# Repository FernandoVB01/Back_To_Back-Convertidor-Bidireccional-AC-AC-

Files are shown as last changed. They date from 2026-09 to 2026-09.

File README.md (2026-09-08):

# Convertidor Back-to-Back (AFE + Inversor) — 15 kVA / 800 V

Convertidor trifásico regenerativo completo: rectificador activo (AFE) +
inversor con control vectorial, bus DC común, control en **STM32G474** y
telemetría en **ESP32-S3**. Diseño en KiCad 9, validado por simulación.

**Punto de diseño:** 15 kVA · 400 V_LL · 60 Hz · V_dc ≤ 800 V · f_sw 16 kHz.

---

## Cómo lo ejecuto

```powershell
powershell -ExecutionPolicy Bypass -File .\run.ps1
```

Eso hace **todo** en orden. Tarda unos minutos (lo más lento es LTspice).

Por etapas, si solo quieres una parte:

```powershell
.\run.ps1 check    # comprobar que están las herramientas (empieza por aquí)
.\run.ps1 sim      # simulación y validación   -> docs/INFORME_VALIDACION.md
.\run.ps1 spice    # LTspice                   -> sim/out/06..08*.png
.\run.ps1 fw       # firmware: genera b2b_config.h
.\run.ps1 kicad    # esquemático + PCB + render 3D
.\run.ps1 mech     # gabinete
```

### ⚠ Lo único que hay que entender: hay DOS Python

No son intercambiables. `run.ps1` elige el correcto en cada paso, pero si
lanzas algo a mano tienes que saberlo:

| Python | Dónde | Para qué |
|---|---|---|
| **El de KiCad** | `C:\Program Files\KiCad\9.0\bin\python.exe` | `tools/gen_schematic.py`, `gen_pcb.py`, `check_conn.py`, `restore_pro.py` — necesitan el módulo `pcbnew` |
| **Anaconda** | `python` (en el PATH) | `sim/`, `spice/`, `mech/`, `fw/`, `tools/gen_kicad_sim.py`, `verify_kicad_sim.py` — necesitan numpy/scipy/matplotlib |

Si un script falla con `ModuleNotFoundError: pcbnew` o
`ModuleNotFoundError: numpy`, es que lo has lanzado con el Python equivocado.

### Requisitos

- **KiCad 9.0** en `C:\Program Files\KiCad\9.0` (trae su Python y `kicad-cli`)
- **Anaconda** con numpy, scipy, matplotlib
- **LTspice** (ADI) en `%LOCALAPPDATA%\Programs\ADI\LTspice\` — solo para la
  etapa `spice`; el resto funciona sin él

---

## Qué hay en cada carpeta

```
kicad/      PROYECTO KICAD  <- abre b2b_converter.kicad_pro
  sch/        11 subhojas del esquemático
  sim/        esquemas simulables con ngspice (Inspeccionar > Simulador)
sim/        simulación y validación en Python (la fuente de la verdad)
spice/      netlists de LTspice (se abren también a mano en LTspice)
fw/         firmware del STM32G474
mech/       gabinete industrial
tools/      los generadores (nada de esto se editó a mano)
docs/       toda la documentación
render/     renders 3D de la PCB
export/     PDF de los planos, informes de ERC y DRC
```

## Por dónde empezar a leer

| Documento | Qué te cuenta |
|---|---|
| [docs/INFORME_VALIDACION.md](docs/INFORME_VALIDACION.md) | Las 31 comprobaciones del diseño, con los números |
| [docs/ESTADO_KICAD.md](docs/ESTADO_KICAD.md) | Qué está hecho en la PCB y qué falta |
| [docs/BOM_INDUSTRIAL.md](docs/BOM_INDUSTRIAL.md) | Componentes con marca y referencia real |
| [docs/COMO_SIMULAR.md](docs/COMO_SIMULAR.md) | **Cómo lanzar las 4 simulaciones y qué mirar en cada una** |
| [docs/RUTEO_ESTADO.md](docs/RUTEO_ESTADO.md) | Estado del ruteo y los bugs que destapó |
| [docs/SIMULAR_FIRMWARE.md](docs/SIMULAR_FIRMWARE.md) | Por qué Proteus no sirve aquí y qué se hace en su lugar |
| [docs/00_MASTER_PLAN.md](docs/00_MASTER_PLAN.md) | Arquitectura y las 6 fases del proyecto |
| [docs/KICAD_PCB_FLOORPLAN.md](docs/KICAD_PCB_FLOORPLAN.md) | Stackup, floorplan y orden de ruteo |

---

## La regla de oro del proyecto

**Todo sale de `sim/b2b_params.py`.** Ese archivo es la única fuente de
parámetros:

```
sim/b2b_params.py
   ├──► sim/run_all.py        ──► validación (31 comprobaciones)
   ├──► spice/gen_spice.py    ──► SPICE
   ├──► fw/config/gen_config.py ──► b2b_config.h ──► firmware C
   │                                     └──► control_ref.py (verificación)
   ├──► tools/gen_schematic.py ──► esquemático KiCad
   └──► mech/gen_gabinete.py  ──► gabinete
```

Si cambias un parámetro ahí y ejecutas `.\run.ps1`, se regenera todo y nada
se desincroniza. **No edites a mano el esquemático ni `b2b_config.h`**: los
sobrescribe el generador.

## Estado

- Esquemático: **227 componentes**, 0 cables sueltos. Bus DC corregido:
  `DC_P` pasó de 4 a **22 pads** (los rieles solo conectaban la última rama)
- PCB: 340×240 mm, 4 capas, footprints colocados y zonas rellenadas
- **Ruteo de pistas: 0 %** — ver [docs/RUTEO_ESTADO.md](docs/RUTEO_ESTADO.md): el auto-ruteador propio se descartó por introducir cortocircuitos
- Validación: **31/31 comprobaciones OK**
- Firmware: matemática de control y configuración listas; falta la capa HAL

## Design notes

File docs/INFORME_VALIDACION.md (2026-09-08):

# Informe de validacion del convertidor back-to-back

> Generado por `sim/run_all.py`. No editar a mano: cambia `sim/b2b_params.py` y vuelve a ejecutarlo.

```
PUNTO DE DISENO
  S = 15 kVA | 400 V_LL | 60 Hz | I_n = 21.65 A
  Bus DC = 700 V (max 800 V) | C_bus = 600 uF
  f_sw = 16 kHz | T_s = 62.5 us | dead-time = 500 ns
  LCL: L1 = 1.50 mH | Cf = 10.0 uF | Rd = 6.8 ohm | L2 = 0.60 mH
  SiC: C3M0075120K (75 mOhm) x 12
  Motor: PMSM p=3 lambda=0.35 Wb Kt=1.575 Nm/A J=0.02 kg m2
```

## Resultado global

**38 de 38 comprobaciones OK.**

## 1. Filtro LCL y calidad de red

| | Comprobacion | Valor | Limite | Nota |
|:-:|---|---:|---:|---|
| **OK** | Resonancia LCL | 2431 Hz | 600 .. 8000 | debe estar entre 10*fg y fsw/2 |
| **OK** | Atenuacion extra a f_sw vs L unica | -15.853 dB | -12.000 | compromiso con el amortiguamiento; el criterio normativo real es la THD |
| **OK** | Rizado en L1 (pico-pico) | 11.907 % | 25.000 | 3.65 A sobre 30.6 A pico |
| **OK** | Reactiva del banco Cf | 4.021 % | 5.000 | 603 var |
| **OK** | Pico en resonancia (amortiguado) | 19.200 dB | 20.000 | sin Rd seria 69 dB |
| **OK** | Disipacion en las 3 Rd | 12.202 W | 30.000 | usar 10 W por resistencia |
| **OK** | THD de corriente de red (estimada) | 0.245 % | 5.000 | IEEE 519 / IEC 61000-3-12 |

## 2. Estabilidad de los lazos de control

| | Comprobacion | Valor | Limite | Nota |
|:-:|---|---:|---:|---|
| **OK** | Lazo de corriente: ancho de banda | 849.389 Hz | 800 .. 2667 | Kp = 11.200  Ki = 266.7 |
| **OK** | Lazo de corriente: margen de fase | 61.333 grados | 45.000 |  |
| **OK** | Lazo de corriente: margen de ganancia | 9.934 dB | 6.000 |  |
| **OK** | Lazo de bus DC: ancho de banda | 141.425 Hz | 10 .. 169.9 | Kp = 0.7623  Ki = 225.946 |
| **OK** | Lazo de bus DC: margen de fase | 53.130 grados | 45.000 |  |

## 3. Termico (C3M0075120K, el de la libreria)

| | Comprobacion | Valor | Limite | Nota |
|:-:|---|---:|---:|---|
| **OK** | Perdidas por dispositivo (C3M0075120K) | 28.131 W | 40.000 | cond 22.8 + conm 4.1 + diodo 1.3 |
| **OK** | Perdidas totales de semiconductores | 337.577 W | 400.000 | 12 dispositivos |
| **OK** | Rth disipador-ambiente requerida | 0.162 C/W | 0.150 | por debajo de 0.15 C/W ya no es viable con aire |
| **OK** | Rendimiento estimado | 97.418 % | 96.000 |  |

## 3b. Termico (C3M0040120K, el recomendado)

| | Comprobacion | Valor | Limite | Nota |
|:-:|---|---:|---:|---|
| **OK** | Perdidas por dispositivo (C3M0040120K) | 17.514 W | 40.000 | cond 12.1 + conm 4.1 + diodo 1.3 |
| **OK** | Perdidas totales de semiconductores | 210.169 W | 400.000 | 12 dispositivos |
| **OK** | Rth disipador-ambiente requerida | 0.306 C/W | 0.150 | por debajo de 0.15 C/W ya no es viable con aire |
| **OK** | Rendimiento estimado | 98.231 % | 96.000 |  |

## 4. Precarga del bus

| | Comprobacion | Valor | Limite | Nota |
|:-:|---|---:|---:|---|
| **OK** | Corriente de inrush | 8.319 A | 10.000 |  |
| **OK** | Constante de tiempo de precarga | 40.800 ms | 200.000 | 95 % en 122 ms |
| **OK** | Energia en Rpc por carga | 96.000 J | 400.000 | pico instantaneo 4.7 kW |

## 5. Simulacion temporal + frenado regenerativo

| | Comprobacion | Valor | Limite | Nota |
|:-:|---|---:|---:|---|
| **OK** | Error de regulacion del bus (motorizando) | 0.0006843 % | 1.000 | media 700.0 V |
| **OK** | Rizado del bus en regimen | 0.00455 % | 2.000 |  |
| **OK** | Pico de bus durante el frenado | 701.611 V | 800.000 | chopper en 770 V, disparo en 800 V |
| **OK** | Factor de potencia en la red | 1.000  | 0.990 | Id = 21.06 A, Iq = -0.000 A |
| **OK** | Potencia de red motorizando | 10.315 kW | 0.000 | positiva = consume de la red |
| **OK** | Potencia de red frenando | -5.938 kW | 0.000 | NEGATIVA = devuelve a la red (regenera) |
| **OK** | Error maximo del PLL tras enganche | 6.183e-12 grados | 1.000 |  |
| **OK** | Error de velocidad en regimen | 9.368e-05 % | 2.000 | 250.0 rad/s de 250 rad/s |

## 6. Respuesta dinamica, rendimiento y armonicos

| | Comprobacion | Valor | Limite | Nota |
|:-:|---|---:|---:|---|
| **OK** | Sobreimpulso del lazo de corriente | 4.052 % | 20.000 |  |
| **OK** | Tiempo de establecimiento del bus | 8.862 ms | 50.000 | al 2 % |
| **OK** | Caida del bus ante escalon de carga (con FF) | 6.326 V | 14.000 | limite 2 % = 14 V |
| **OK** | Margen de modulo (distancia a -1) | 0.629  | 0.500 | > 0.5 es robusto |
| **OK** | THD con armonicos de baja frecuencia | 1.209 % | 5.000 | IEEE 519 |

## 7. Modulacion SVPWM

| | Comprobacion | Valor | Limite | Nota |
|:-:|---|---:|---:|---|
| **OK** | SVPWM: error del lugar geometrico en el limite lineal | 5.125e-10 % | 1.000 | debe ser un circulo de radio Vdc/sqrt(3) |
| **OK** | SVPWM: ganancia sobre SPWM senoidal | 15.470 % | 15.000 | teorico 15.47 % |

## Ganancias resultantes (llevar al firmware)

```c
/* Lazo de corriente del AFE y del inversor, 16 kHz */
#define KP_I     11.200000f
#define KI_I     266.666667f
/* Lazo externo de tension de bus */
#define KP_VDC   0.762316f
#define KI_VDC   225.946265f
#define TS       0.000062500f  /* 62.50 us */
```

## Figuras

### Respuesta del filtro LCL: resonancia, amortiguamiento y atenuacion a f_sw.

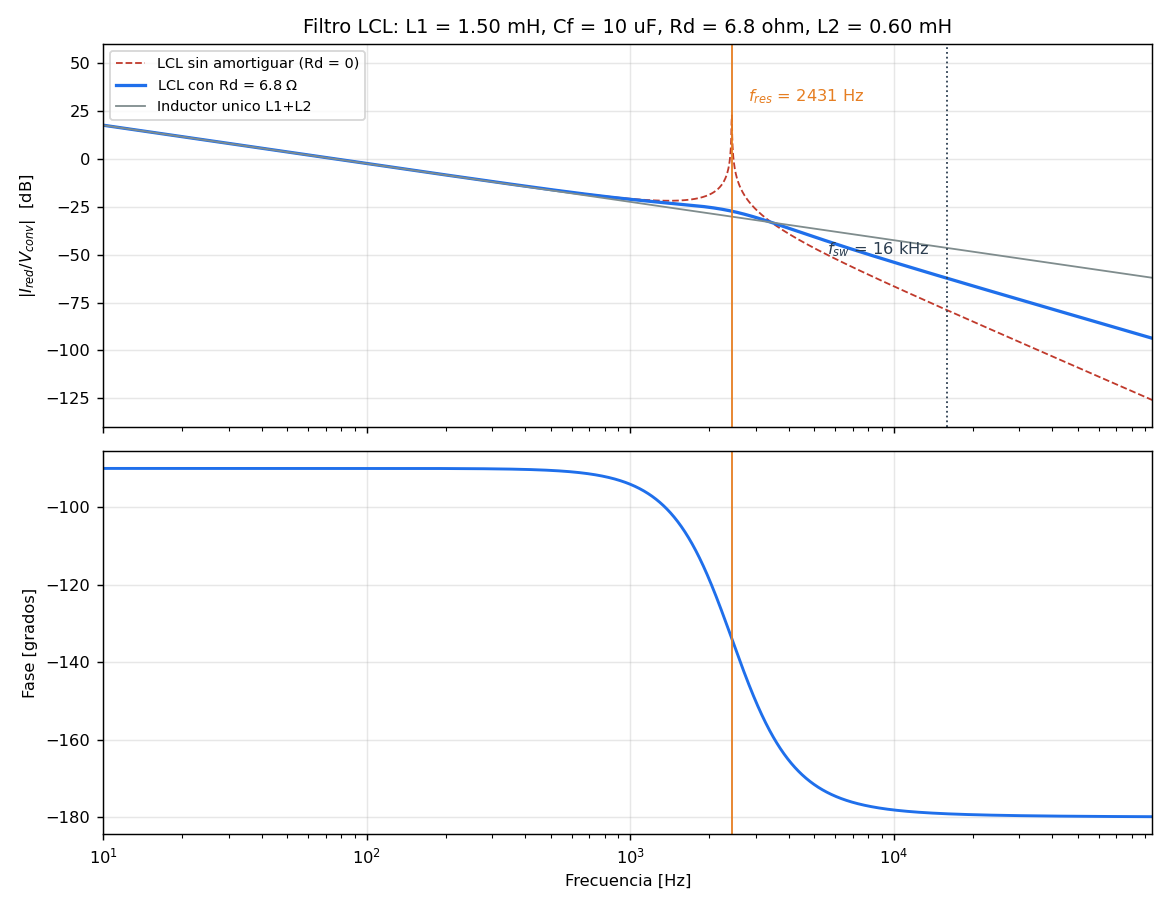
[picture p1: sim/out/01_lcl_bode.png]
Respuesta del filtro LCL: resonancia, amortiguamiento y atenuacion a f_sw.


### Bode de lazo abierto de los lazos de corriente y de bus, con el retardo de 1.5 Ts.

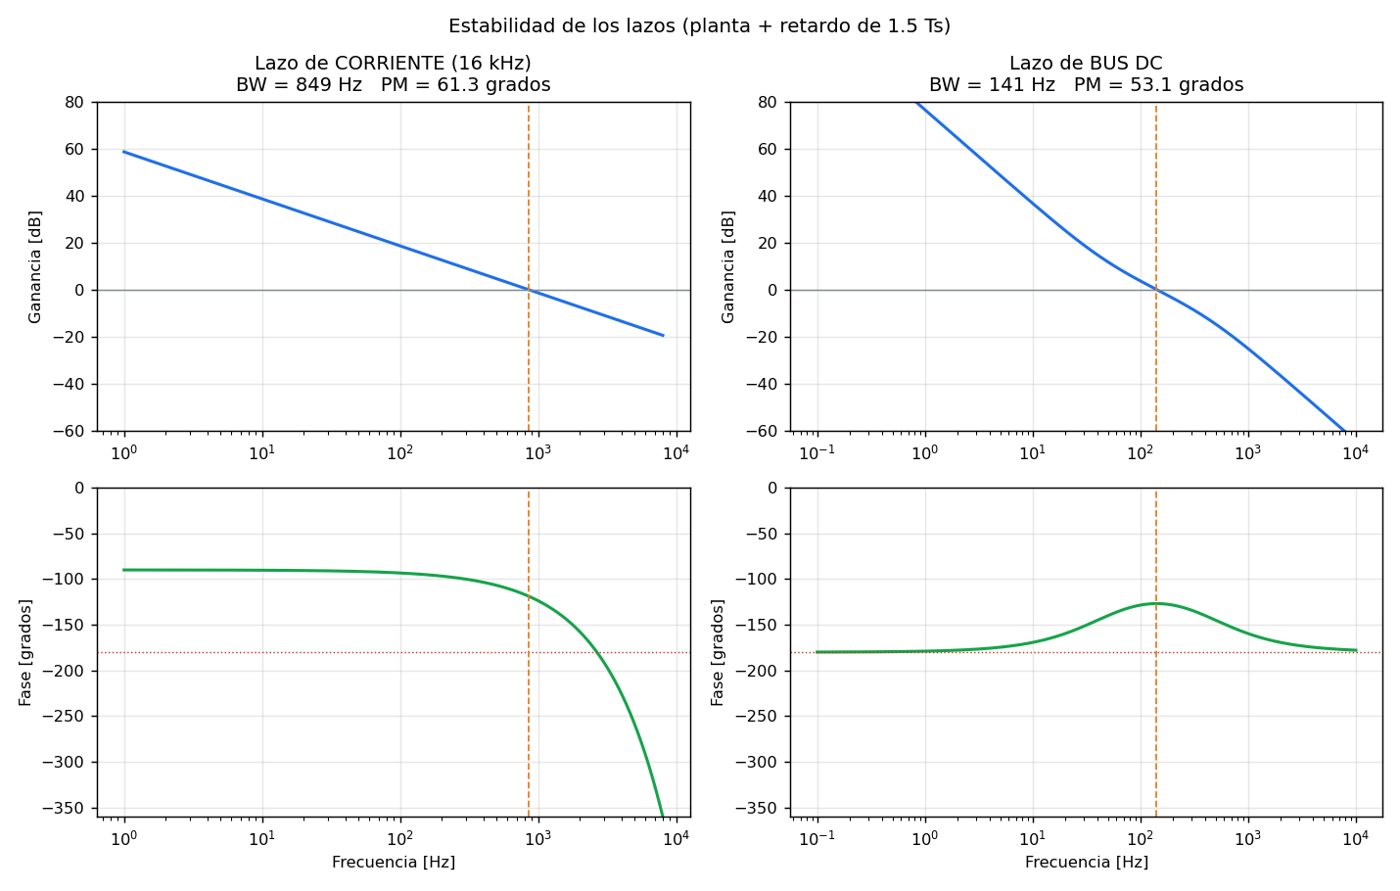
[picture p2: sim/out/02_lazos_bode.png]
Bode de lazo abierto de los lazos de corriente y de bus, con el retardo de 1.5 Ts.


### Transitorio de precarga: tension de bus e inrush.

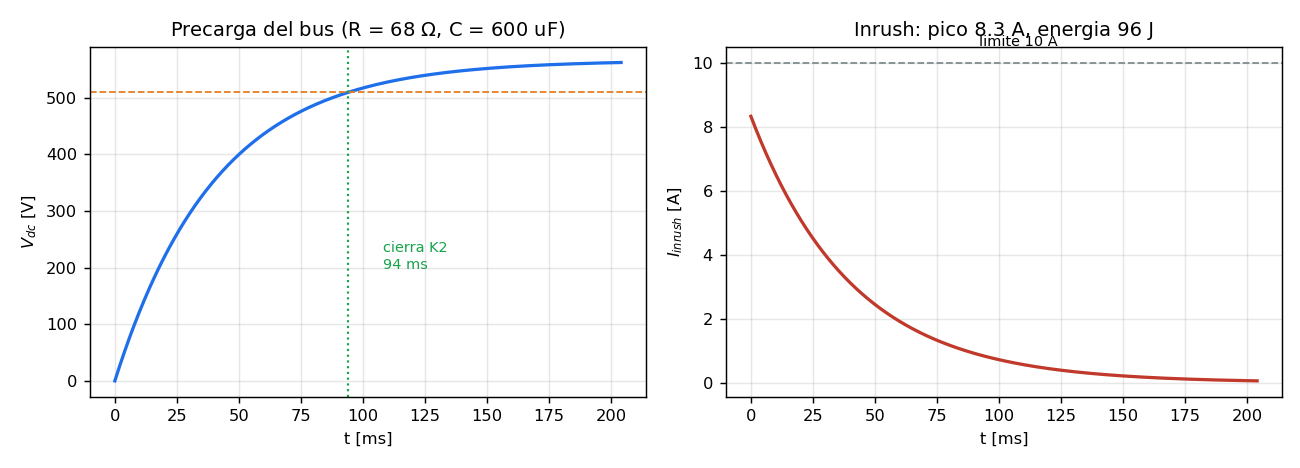
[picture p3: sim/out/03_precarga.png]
Transitorio de precarga: tension de bus e inrush.


### Simulacion completa: bus, motor, flujo de potencia y corriente dq de red.

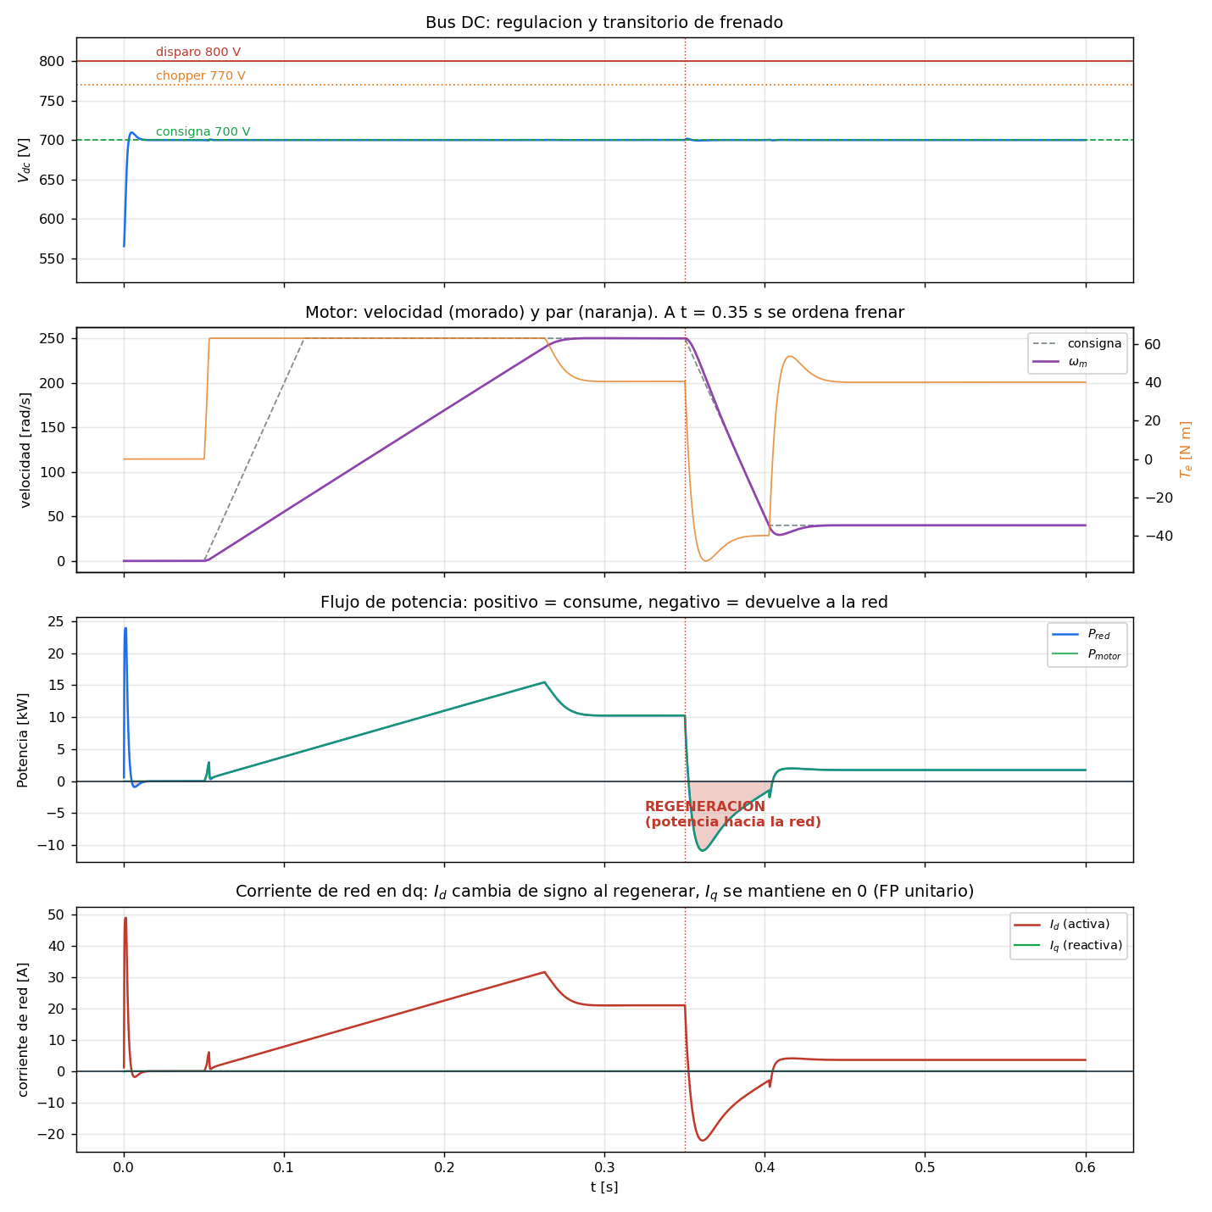
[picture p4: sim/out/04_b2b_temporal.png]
Simulacion completa: bus, motor, flujo de potencia y corriente dq de red.


### Prueba del frenado regenerativo: la corriente de red se invierte.

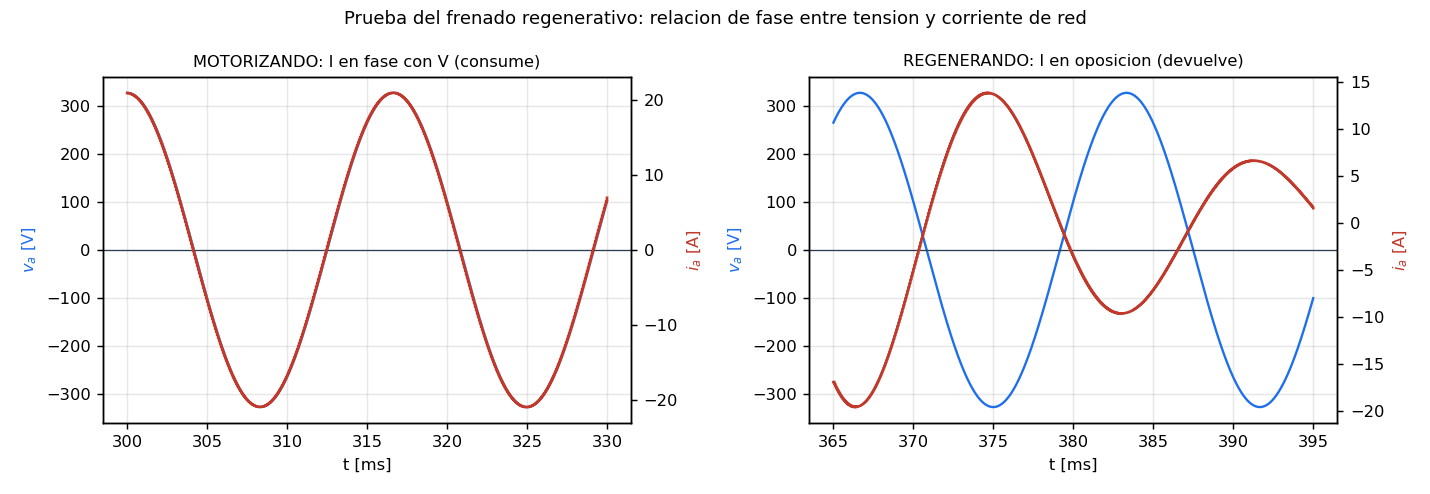
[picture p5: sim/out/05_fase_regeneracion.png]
Prueba del frenado regenerativo: la corriente de red se invierte.


### Respuesta al escalon en lazo cerrado: sobreimpulso y tiempo de establecimiento.

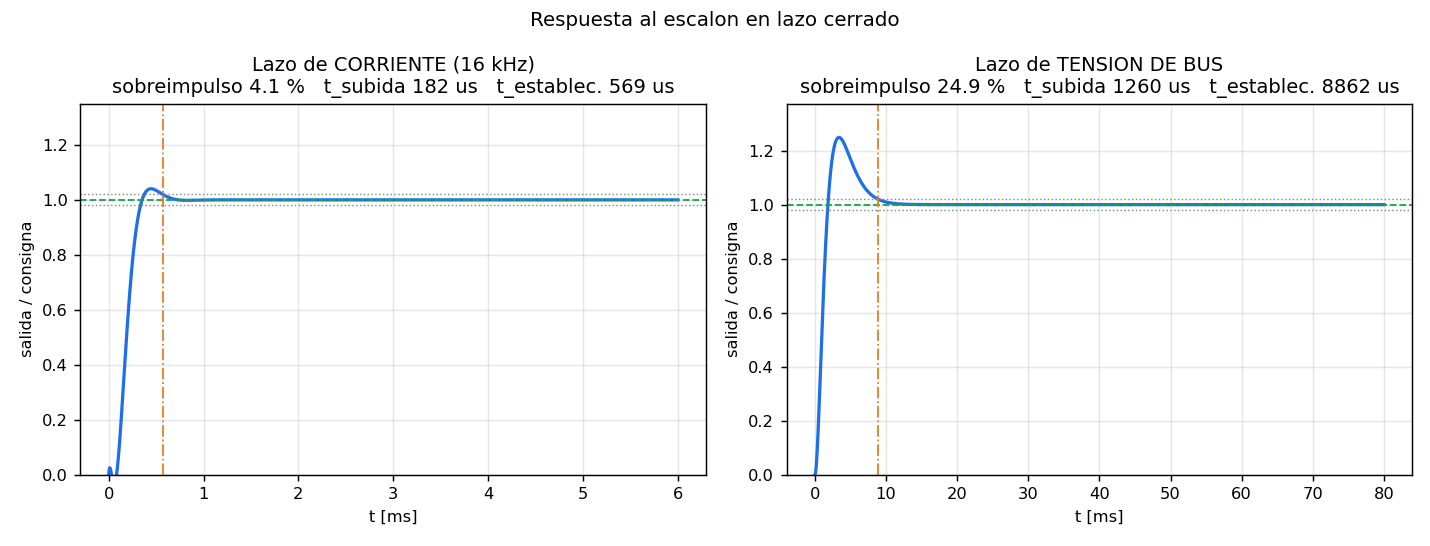
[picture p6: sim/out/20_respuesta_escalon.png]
Respuesta al escalon en lazo cerrado: sobreimpulso y tiempo de establecimiento.


### CARGA TRANSITORIA: escalon de 20 % a 100 % y vuelta. Con y sin feedforward.

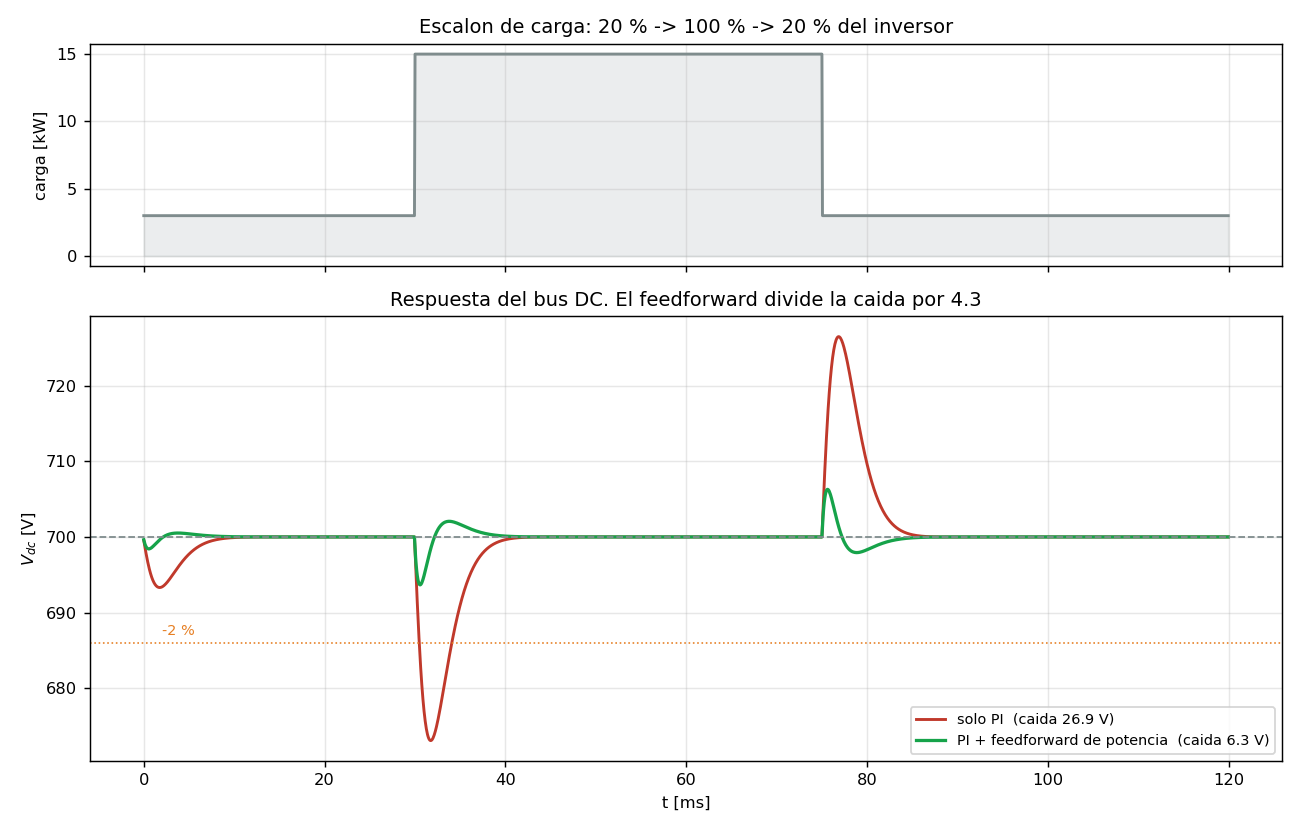
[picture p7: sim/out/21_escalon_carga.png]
CARGA TRANSITORIA: escalon de 20 % a 100 % y vuelta. Con y sin feedforward.


### Nyquist del lazo de corriente con el margen de modulo.

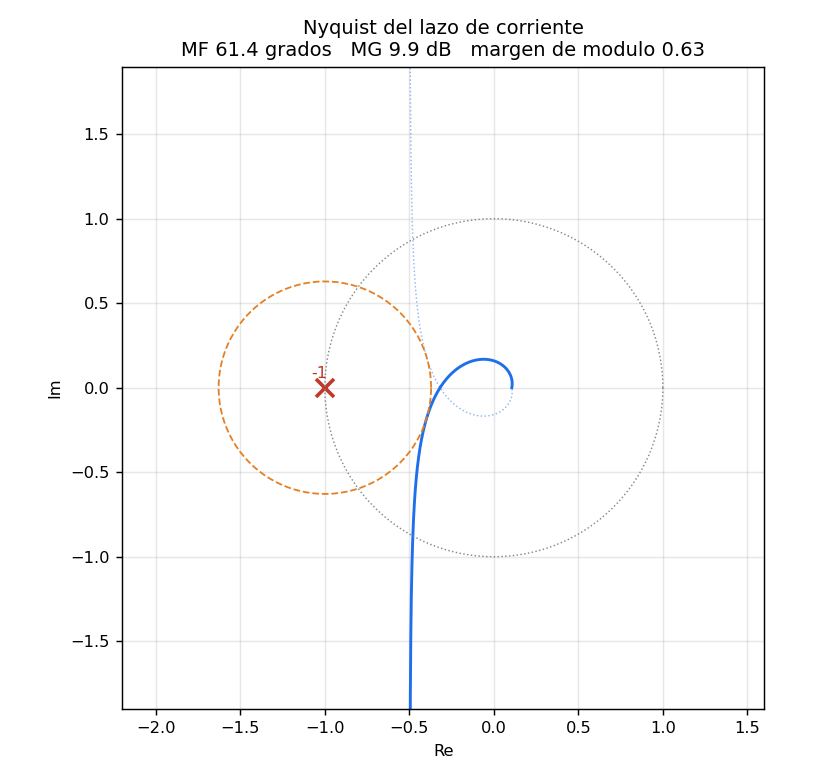
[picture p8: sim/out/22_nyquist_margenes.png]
Nyquist del lazo de corriente con el margen de modulo.


### Rendimiento vs carga y desglose de perdidas.

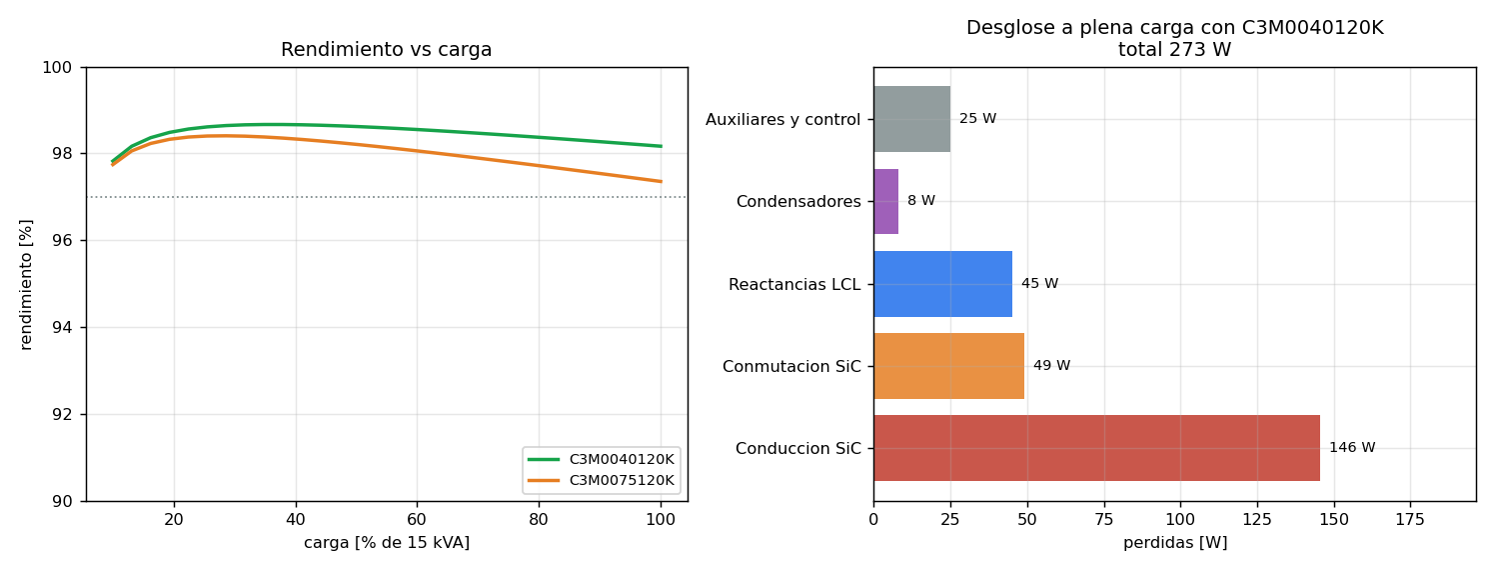
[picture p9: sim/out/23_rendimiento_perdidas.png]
Rendimiento vs carga y desglose de perdidas.


### Temperatura de union vs ambiente y curva de derating.

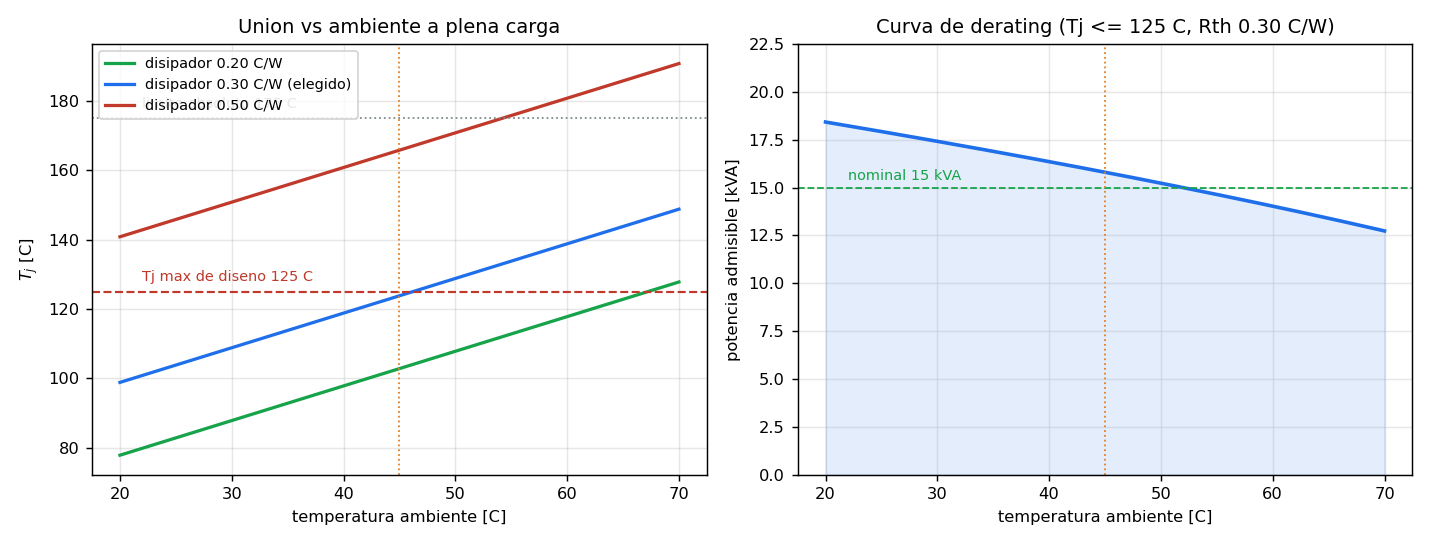
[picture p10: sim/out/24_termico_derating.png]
Temperatura de union vs ambiente y curva de derating.


### Espectro de la corriente de red contra los limites de IEEE 519.

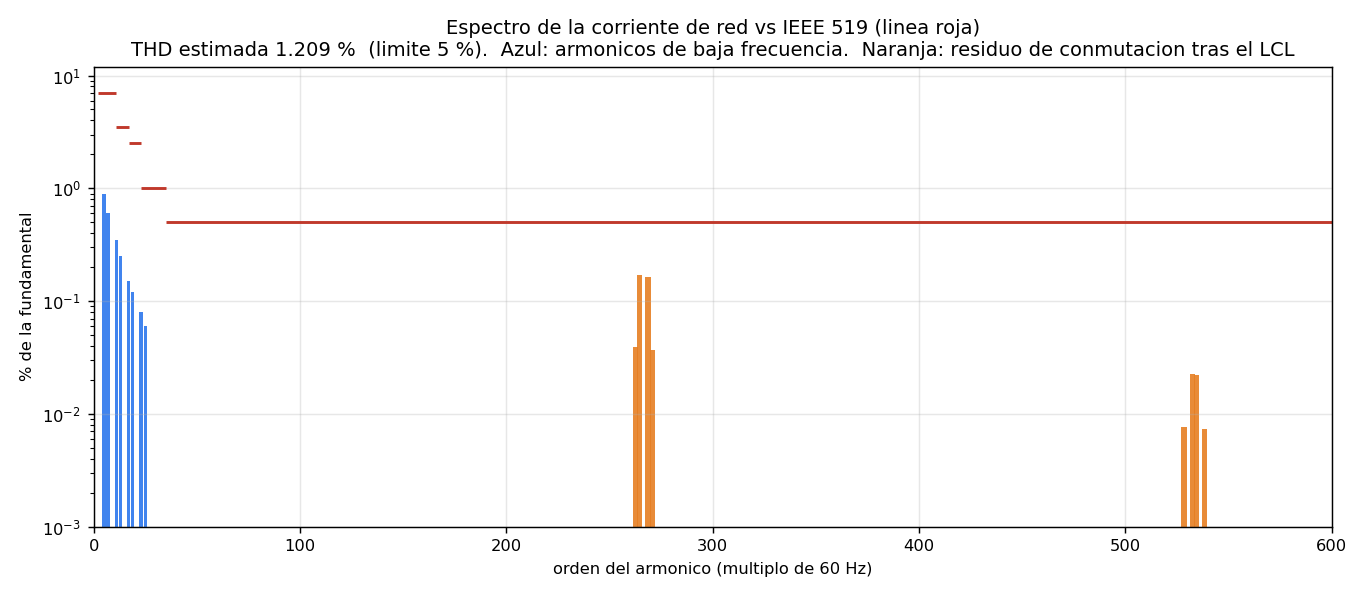
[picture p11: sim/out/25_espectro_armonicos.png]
Espectro de la corriente de red contra los limites de IEEE 519.


### SVPWM: hexagono, 6 sectores y los 8 estados. El lugar geometrico lo genera la funcion svpwm() del firmware.

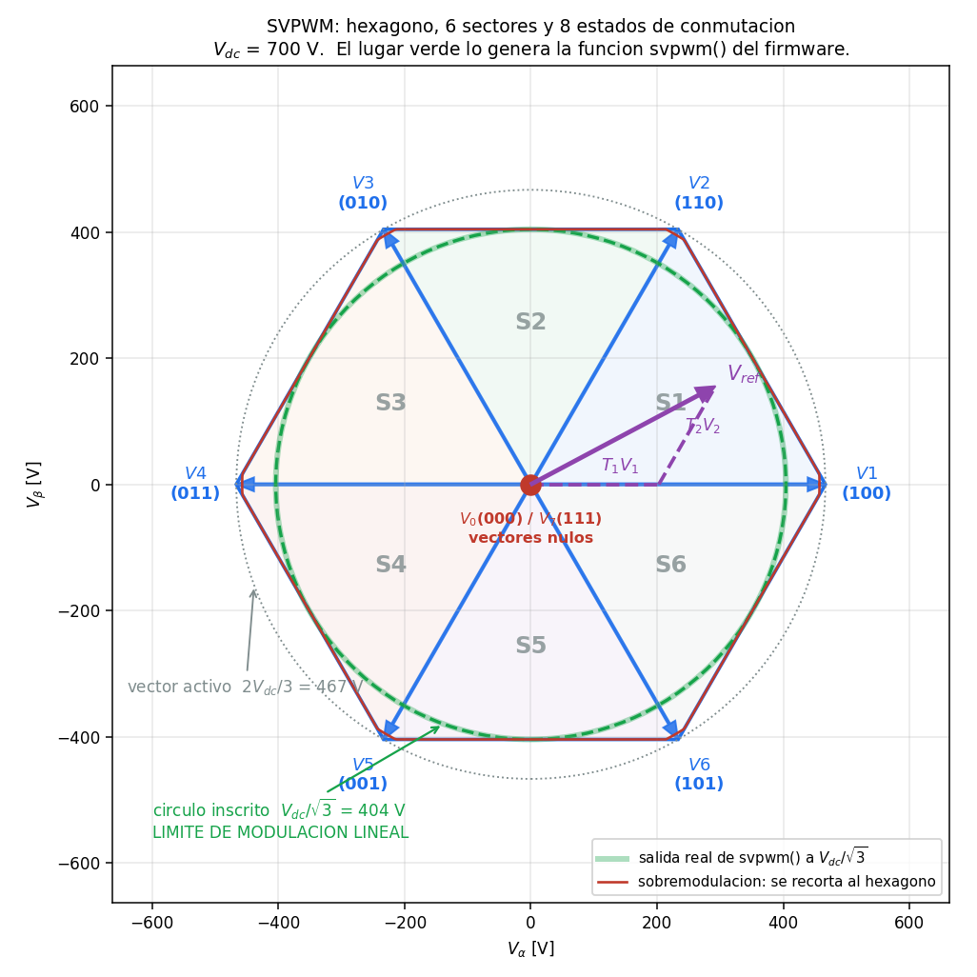
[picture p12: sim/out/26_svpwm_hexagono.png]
SVPWM: hexagono, 6 sectores y los 8 estados. El lugar geometrico lo genera la funcion svpwm() del firmware.


### Ciclos de trabajo vs angulo y patron simetrico de 7 segmentos en un periodo.

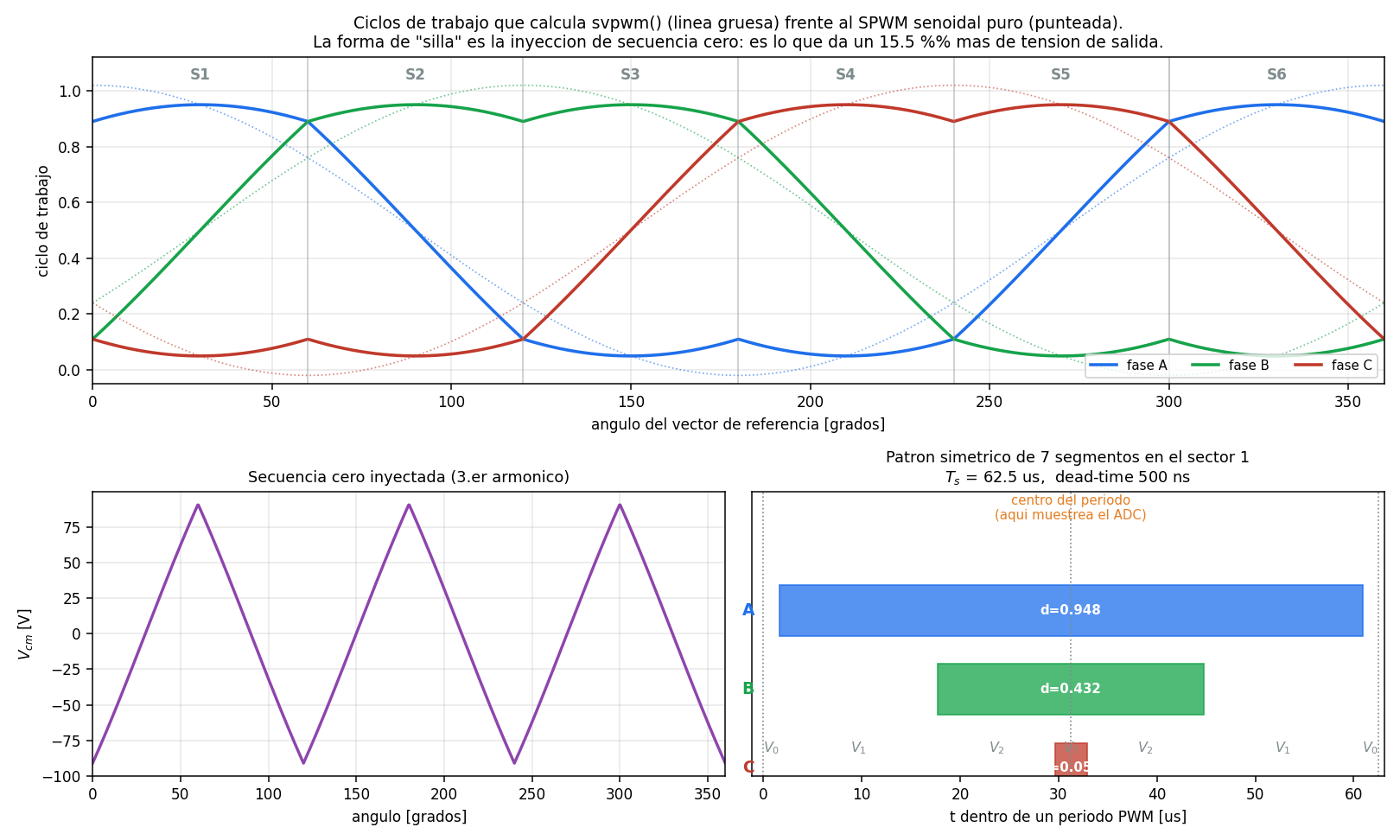
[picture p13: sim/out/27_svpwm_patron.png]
Ciclos de trabajo vs angulo y patron simetrico de 7 segmentos en un periodo.


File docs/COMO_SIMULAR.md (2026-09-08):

# Cómo ejecutar todas las simulaciones

> Hay **cuatro simuladores** distintos en este proyecto y cada uno responde a
> una pregunta diferente. Aquí está qué corre cada uno, cómo lanzarlo y qué
> deberías ver.

---

## Resumen: los cuatro simuladores

| # | Simulador | Responde a | Tarda |
|---|---|---|---|
| 1 | **Python** (`sim/`) | ¿El convertidor completo funciona? ¿Regenera de verdad? | 4 s |
| 2 | **LTspice** (`spice/`) | ¿Cuánta sobretensión mete el layout? ¿Cuál es el dv/dt real? | 2 min |
| 3 | **ngspice dentro de KiCad** (`kicad/sim/`) | Lo mismo, pero sobre el esquema dibujado | interactivo |
| 4 | **SIL del firmware** (`fw/verify/`) | ¿El código de control calcula bien? | 1 s |

**Todo de golpe:**

```powershell
powershell -ExecutionPolicy Bypass -File .\run.ps1
```

---

## 1. Simulación del sistema completo (Python)

La más importante: red → filtro LCL → AFE con PLL → bus DC → inversor con FOC
→ motor PMSM, con un **evento de frenado regenerativo**.

```powershell
.\run.ps1 sim
```
o directamente:
```powershell
python sim/b2b_params.py      # punto de diseno, solo imprime
python sim/sim_design.py      # figuras 01-03 (LCL, lazos, precarga)
python sim/sim_timedomain.py  # figuras 04-05 (convertidor completo)
python sim/sim_respuesta.py   # figuras 20-25 (escalon, Nyquist, termico)
python sim/sim_svpwm.py       # figuras 26-27 (hexagono y patron)
python sim/run_all.py         # todo + el informe
```

**Qué produce**
- `docs/INFORME_VALIDACION.md` — las 38 comprobaciones con sus números
- `sim/out/01_lcl_bode.png` — respuesta del filtro LCL
- `sim/out/02_lazos_bode.png` — Bode de los lazos con el retardo de 1.5·Ts
- `sim/out/03_precarga.png` — transitorio de precarga e inrush
- `sim/out/04_b2b_temporal.png` — **la simulación completa**
- `sim/out/05_fase_regeneracion.png` — tensión vs corriente de red

**Qué mirar en `04_b2b_temporal.png`** (de arriba abajo):
1. El bus DC clavado en **700 V**, sin acercarse ni al chopper (770) ni al disparo (800)
2. El motor acelerando a 250 rad/s; a t = 0.35 s se ordena frenar
3. La potencia de red cruzando a **negativo (−11 kW)** → está devolviendo a la red
4. `Id` cambiando de signo mientras `Iq` sigue en 0 → **factor de potencia unitario**

Debe terminar en **`38/38 OK`**. Si alguna falla, el informe dice cuál y por qué.

### Cambiar el punto de diseño

Todo sale de `sim/b2b_params.py`. Cambia ahí la potencia, la tensión de red,
`f_sw`, los valores del LCL… y vuelve a lanzar. Se regeneran también el SPICE,
el `b2b_config.h` del firmware, el esquemático y el gabinete.

### Lanzar una sola parte

Cada modulo de `sim/` se ejecuta por separado y genera solo sus figuras.
**Ojo: hay que anteponer `python`** — un `.py` no es un comando de Windows.

```powershell
python sim/b2b_params.py      # punto de diseno, solo imprime
python sim/sim_design.py      # figuras 01-03 (LCL, lazos, precarga)
python sim/sim_timedomain.py  # figuras 04-05 (convertidor completo)
python sim/sim_respuesta.py   # figuras 20-25 (escalon, Nyquist, termico)
python sim/sim_svpwm.py       # figuras 26-27 (hexagono y patron)
python sim/run_all.py         # todo + el informe
```

Escribir solo `sim_design.py` da
`no se reconoce como un comando interno o externo`: Windows no ejecuta
scripts de Python directamente.

---

## 2. SPICE en LTspice

Lo que el modelo promediado no puede dar: el transitorio de conmutación real
con las **inductancias parásitas del layout**.

```powershell
.\run.ps1 spice
```
o:
```powershell
python spice\gen_spice.py
```

**Qué produce**
- `sim/out/06_spice_halfbridge.png` — sobretensión según la inductancia de lazo
- `sim/out/07_spice_lcl.png` — contraste del LCL: analítico vs SPICE
- `sim/out/08_spice_precarga.png` — precarga
- `spice/net/*.net` — los netlists, que **se pueden abrir a mano en LTspice**

**El resultado clave** (doble pulso a 700 V / 30 A):

| Inductancia de lazo | Pico en el nodo de conmutación |
|---:|---:|
| 5 nH | 753 V |
| **20 nH** (objetivo del floorplan) | **823 V** |
| 60 nH | 929 V |
| 150 nH | 1136 V ← al borde de romper el SiC de 1200 V |

Eso es lo que justifica numéricamente la regla de "lazo apretado".

### Abrirlos a mano en LTspice

```powershell
& "$env:LOCALAPPDATA\Programs\ADI\LTspice\LTspice.exe" spice\net\hb_20nH.net
```
Una vez abierto: **Simulate → Run**, y click en un nodo para graficarlo.

---

## 3. ngspice dentro de KiCad

Los mismos circuitos, pero dibujados como esquema de KiCad.

```powershell
python tools\gen_kicad_sim.py
```

Genera tres esquemas en `kicad/sim/`:

| Archivo | Análisis | Qué comprueba |
|---|---|---|
| `lcl_ac.kicad_sch` | `.ac dec 400 10 200k` | Resonancia en 2431 Hz, pico amortiguado de 19 dB |
| `halfbridge.kicad_sch` | `.tran 0.02n 5.2u` | Sobretensión según la parásita del lazo |
| `fw_bridge.kicad_sch` | `.tran 100n 187u` | Puente gobernado por el **PWM real del firmware** |

**Para simularlos:**
1. Abre el `.kicad_sch` en KiCad (doble clic)
2. **Inspeccionar → Simulador**
3. Botón **Ejecutar**
4. **Añadir señales** y elige qué graficar: `I(RL2)` en el LCL, `V(sw)` en el medio puente

El comando de análisis va escrito como texto en la propia hoja; puedes
editarlo ahí mismo.

### El interesante: `fw_bridge`

Sus seis fuentes de puerta **no son ondas inventadas**: son los flancos que
calcula el código de control real (SVPWM por inyección de secuencia cero) con
el dead-time de 500 ns del TIM1. KiCad **no ejecuta firmware** — no tiene
modelo de núcleo ARM — pero aquí su salida real gobierna el circuito.
Ver `docs/SIMULAR_FIRMWARE.md`.

### Verificación cruzada automática

```powershell
python tools\verify_kicad_sim.py
```
Exporta el netlist SPICE desde el esquema de KiCad, lo ejecuta y lo compara
con el modelo analítico. El LCL debe coincidir en **menos de 1 dB**.

---

## 4. SIL del firmware

Comprueba que la matemática de control es correcta y que las constantes del
firmware están sincronizadas con la simulación.

```powershell
.\run.ps1 fw
```
o:
```powershell
python sim/b2b_params.py      # punto de diseno, solo imprime
python sim/sim_design.py      # figuras 01-03 (LCL, lazos, precarga)
python sim/sim_timedomain.py  # figuras 04-05 (convertidor completo)
python sim/sim_respuesta.py   # figuras 20-25 (escalon, Nyquist, termico)
python sim/sim_svpwm.py       # figuras 26-27 (hexagono y patron)
python sim/run_all.py         # todo + el informe
```

**Qué deberías ver**
```
f_sw pedida = 16000.0 Hz   ARR = 5312   ->  f_sw real = 16001.51 Hz
dead-time pedido = 500 ns  DTG = 85 (0x55)  ->  real = 500.0 ns
SVPWM a modulacion lineal maxima -> duties 0.9330 0.0670 0.0670
```

Esos *duties* de 0.933/0.067 son exactamente el límite lineal del SVPWM
(±√3/4). Si salen otros, la modulación está mal.

---

## 5. El gabinete

```powershell
.\run.ps1 mech
```
Genera `mech/out/gabinete_frontal.png` y `gabinete_lateral.png`, y calcula la
ventilación: **298 W internos → hace falta ventilación forzada** (por
convección natural el interior llegaría a 65 °C).

---

## Si algo falla

**`ModuleNotFoundError: numpy`** → lanzaste con el Python de KiCad. Usa
`python` (Anaconda).

**`ModuleNotFoundError: pcbnew`** → al revés: usa
`"C:\Program Files\KiCad\9.0\bin\python.exe"`.

**`LTspice no encontrado`** → comprueba la ruta con `.\run.ps1 check`. Solo
afecta a la etapa `spice`; el resto funciona sin él.

**El `.raw` ocupa 100 MB** → normal en el puente trifásico: con 6 SiC
conmutando, LTspice refina el paso hasta el femtosegundo. Los esquemas de
`kicad/sim/` llevan una directiva `.save` para limitarlo.

**Comprobar el entorno entero:**
```powershell
.\run.ps1 check
```

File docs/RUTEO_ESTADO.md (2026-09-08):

# Ruteo de la PCB — qué se intentó, qué funcionó y qué no

> Documento honesto sobre el intento de auto-ruteo. **Resumen: no se ruteó.**
> Se encontró y corrigió un error grave de colocación, y el auto-ruteador
> propio se descartó por no cumplir el listón de seguridad.

---

## 1. El hallazgo importante: los gate drivers estaban mal orientados

Al analizar qué redes se podían rutear apareció un **error real de diseño**,
no del ruteador.

El `UCC21520DW` es un SOIC-16W con la **lógica en los pines 1-8** y la
**potencia en los pines 9-16**. Es decir: la barrera de aislamiento del
encapsulado va **entre sus dos filas de pines**.

Estaban colocados con `rot=0`, lo que dejaba:

| Pad | Red | Dónde caía |
|---|---|---|
| 1, 2 | `PWM_H1`, `PWM_L1` (lógica) | y = 143.6 → **lado HV** |
| 8, 9 | `+5V`, `K_L1` (potencia) | y = 152.4 → lado LV |
| 3,4,5,11,14 | varias | **dentro de la franja de aislamiento** |

Con esa orientación, `PWM_H1` tenía que ir desde el lado HV del driver hasta
el STM32 en la zona LV: **cruzando la barrera de aislamiento**. No es una
incomodidad de ruteo, es una violación de aislamiento.

**Corrección: `rot=90`.** Deja la lógica (1-8) abajo en zona LV y la potencia
(9-16) arriba en HV, con las dos filas separadas 9.3 mm — la franja de 6 mm
queda limpia entre ellas, sin ningún pad dentro.

Efecto medido:

| | Antes | Después |
|---|---:|---:|
| Redes que cruzan la barrera | 29 | **19** |
| Pads dentro de la franja | 16 | **1** |
| Redes ruteables en su zona | 57 | **82** |

Este solo hallazgo justifica el ejercicio.

## 2. El auto-ruteador propio: descartado

`tools/route_pcb.py` implementa tres pasadas (vías a plano, potencia, señales)
con un ruteador L/Z y detección de colisión por distancia segmento-segmento.
Resultados de la mejor versión:

| | |
|---|---:|
| Ratsnest inicial | 326 |
| Ratsnest tras rutear | 157 |
| Redes completas | 15 de 98 |
| Pistas / vías | 215 / 80 |

**Pero el DRC lo tumbó:**

| Violación introducida | Cantidad |
|---|---:|
| `shorting_items` (cortocircuitos reales) | **37** |
| `clearance` | 106 |
| `holes_co_located` (vías solapadas) | 52 |
| `solder_mask_bridge` | 47 |

**37 cortocircuitos en una placa de 800 V es inaceptable.** Se revirtió.

### Por qué falla

El modelo de obstáculos del ruteador solo conoce pads y sus propias pistas.
No conoce:
- las zonas de cobre rellenadas,
- las reglas DRC reales por clase de red,
- los taladros como objetos que atraviesan **todas** las capas,
- las máscaras de soldadura.

Un ruteador L/Z sin *rip-up and retry* no sirve para la densidad del lado LV
(0603 a 4 mm de paso alrededor de un LQFP-100). Las pasadas 2-3 quedan
**desactivadas por defecto**; para forzarlas: `ROUTE_SIGNALS=1`.

## 3. Estado real de la placa que se entrega

**Colocada, con zonas de cobre, SIN pistas.**

```
Componentes ....... 227      Redes ............. 130
Ratsnest .......... 325      Pistas ............ 0
```

DRC actual: 772 violaciones. Desglose honesto:

| Tipo | N.º | Por qué |
|---|---:|---|
| `unconnected_items` | 325 | **no hay pistas**: es lo esperado |
| `clearance` | 198 | pads **sin red** dentro de las zonas HV (consecuencia de lo anterior) |
| `silk_over_copper` / `silk_overlap` | 199+199 | cosmético: referencias sobre cobre |
| `items_not_allowed` | 71 | pads que aún caen en el área `ISO_BARRIER` |
| `courtyards_overlap` | 46 | colocación automática demasiado densa |
| `solder_mask_bridge` | 27 | deriva de lo anterior |

Un bug real corregido por el camino: la zona de masa de la zona HV se vertía
como **`PGND`, red que no existe en la netlist** (el net-tie NT2 la une a
`GND`). Quedaba como cobre huérfano sin red. Ahora se vierte en `GND`.

## 4. Cómo rutear esto de verdad

Por orden de recomendación:

**a) Ruteador interactivo de KiCad** (lo que haría un diseñador).
Carga primero las reglas: *Configuración de la placa → Reglas custom* →
pegar `kicad/drc_custom_rules.txt`. Luego seguir el orden de
`docs/KICAD_PCB_FLOORPLAN.md` §5: **primero los lazos de conmutación**, que
son los que fijan el EMI de toda la placa.

**b) Freerouting** (autorouter libre, Java ya está instalado en la máquina).
Requiere exportar Specctra DSN desde Pcbnew (*Archivo → Exportar → Specctra
DSN*; `kicad-cli` no lo soporta) y descargar el `.jar`. No se hizo aquí
porque implica descargar y ejecutar software de terceros.

**c) Arreglar el ruteador propio.** Habría que sustituir el L/Z por un
ruteador de laberinto (A* sobre rejilla) con rip-up, y consultar el motor DRC
real de KiCad en vez de un modelo de obstáculos propio. Es un proyecto en sí.

## 5. Bugs de conectividad encontrados AL INTENTAR RUTEAR

Intentar rutear los lazos de conmutacion destapo tres errores graves del
esquematico que ninguna revision visual habia visto:

**a) Los rieles del bus DC solo conectaban la ultima rama.**
`DC_P` tenia 4 pads cuando debia tener 22. Q1, Q3, Q7 y Q9 estaban
`unconnected`. Causa: el riel se dibujaba como UN cable largo y los stubs de
cada rama morian en mitad de el. **KiCad solo une cables extremo con extremo**:
un cable que termina en medio de otro NO conecta, ni poniendo una junction.
Solo funcionaba la ultima rama porque coincidia con el extremo del riel.
Corregido con un helper `rail()` que construye el riel PARTIDO en cada punto
de contacto.

**b) El puente AFE no estaba conectado al filtro LCL.**
El nodo de conmutacion se llamaba `SW_A` y la salida del LCL `AFE_A`: son el
mismo nodo fisico pero con dos nombres, asi que `AFE_A` colgaba sola en `L1A`.
Unificado a `AFE_A/B/C`.

**c) La resistencia de precarga quedaba puenteada.**
Al construir los rieles automaticamente, el helper se tragaba tambien el nodo
`DC_RAW` (antes de `RPC`), poniendo las dos patas de la resistencia en la
misma red. Corregido acotando el riel con `xmin`.

Resultado: `DC_P` paso de **4 a 22 pads**, `DC_N` de 4 a 18, y las redes
`unconnected-*` de 110 a 98.

## 6. Se probo extender el bus laminado y NO funciono

Idea: verter `DC_P` (F.Cu) y `DC_N` (B.Cu) solapados sobre TODA la fila de
potencia, para que el bus llegue a cada medio puente sin pistas.

Resultado: **peor**. 293 violaciones de clearance y 34 cortocircuitos. Con
3 mm exigidos a la clase `HV_DC` y los pines del TO-247-4 a 2.54 mm, el plano
no cabe entre el drenador y la puerta del mismo dispositivo.

Llevar el bus hasta cada rama exige **recortes locales** alrededor de
gate/Kelvin, que es trabajo de ruteo manual en Pcbnew. Se revirtio.

## 7. Antes de rutear, conviene arreglar

1. **`items_not_allowed` (71)**: quedan pads en la franja `ISO_BARRIER`.
   Afinar la colocación de los módulos de bias aislados.
2. **Los 6 DC-DC de bias (`+15VG1H..6H`)**: son secundarios aislados y deben
   ir **a caballo de la barrera** junto a su driver, no en la zona LV. Con la
   huella genérica de 4 pines no encajan: hay que usar la del `MGJ2D152005SC`
   real, que tiene la separación de pines correcta.
3. **`courtyards_overlap` (46)**: separar más en la colocación automática.

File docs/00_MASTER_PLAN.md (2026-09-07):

# Convertidor Back-to-Back (AFE + Inversor Trifásico) con Telemetría IoT
## Plan Maestro de Implementación — Hardware, PCB (KiCad), Firmware y Bring-up

> Documento raíz. Cada fase tiene su archivo propio en `docs/`. Las reglas de
> diseño de KiCad están en `kicad/`. Léelo en orden; no saltes al ruteo sin
> haber cerrado el dimensionamiento.

---

## 0. Filosofía del proyecto

Estás construyendo un **convertidor back-to-back**: dos puentes trifásicos de
2 niveles que comparten un **bus DC** común.

```
   RED 3~                 BUS DC (hasta 800 V)                 MOTOR 3~
 ┌────────┐   ┌──────┐   ┌───────────────┐   ┌──────┐   ┌────────────┐
 │ 400 V  │───│ LCL  │───│  AFE          │═══│ C_dc │═══│  INVERSOR  │───│ PMSM/IM │
 │ 60 Hz  │   │filtro│   │ (rectificador │   │ bank │   │  (FOC)     │
 └────────┘   └──────┘   │  activo PWM)  │   └──┬───┘   └────────────┘
                         └───────────────┘      │
                                          ┌─────┴──────┐
                                          │ Chopper de │  (resistencia de frenado
                                          │ frenado    │   como respaldo)
                                          └────────────┘
```

- El **AFE (Active Front End)** reemplaza al rectificador de diodos. Controla el
  bus DC, impone **factor de potencia unitario** (o el que ordenes) y, sobre
  todo, permite **devolver energía a la red** durante el frenado regenerativo.
- El **inversor** acciona el motor con **Control Orientado al Campo (FOC)**.
- Cuando el motor frena, la energía cinética vuelve al bus DC → el AFE la
  inyecta a la red. El chopper solo actúa si la red cae o el bus se dispara.

**Dos dominios eléctricos, físicamente separados en la PCB:**

| Dominio | Contenido | Referencia |
|---|---|---|
| **Potencia** | LCL, puentes AFE/inversor, bus DC, precarga, drivers de gate (lado caliente) | PGND, rieles de gate flotantes |
| **Control** | STM32, acondicionamiento analógico, ADC, comparadores de protección | AGND / DGND (unidos en un punto) |
| **IoT** | ESP32, Ethernet/Wi-Fi, conectores de campo | IOGND (aislado del control) |

La **barrera de aislamiento galvánico** cruza la PCB de lado a lado: separa
potencia↔control (seguridad, IEC 61800-5-1) y control↔IoT (funcional, anti-ruido).

---

## 1. Punto de diseño ANCLA

Todos los números de las fases usan esta especificación. **Cámbiala por la tuya
y re-ejecuta las fórmulas** — cada cálculo está parametrizado.

| Parámetro | Símbolo | Valor ancla | Nota |
|---|---|---|---|
| Potencia aparente nominal | S | **15 kVA** | dimensiona magnéticos, semiconductores, cobre |
| Tensión de red (línea-línea) | V_LL | **400 V** RMS | si tu red es 220 V_LL, bus ≈ 400–450 V: reescala todo |
| Frecuencia de red | f_g | **60 Hz** | Ecuador; usa 50 Hz si aplica |
| Tensión de fase | V_ph | 231 V RMS | V_LL/√3 |
| Corriente nominal | I_n | **21.65 A** RMS | S/(√3·V_LL) |
| Corriente de pico nominal | I_pk | 30.6 A | √2·I_n |
| Bus DC nominal | V_dc | **700 V** | referencia de regulación del AFE |
| Bus DC máximo (rating componentes) | V_dc,max | **800 V** | umbral de disparo duro |
| Umbral chopper de frenado | V_dc,chop | **760–780 V** | antes del disparo duro |
| Frecuencia de conmutación | f_sw | **16 kHz** | AFE e inversor; viable con SiC |
| Frecuencia lazo de corriente | f_c | **16 kHz** | 1 ejecución por periodo PWM |
| Frecuencia lazo de velocidad/bus | — | **1–2 kHz** | lazo externo |
| Temperatura ambiente de diseño | T_a | **45 °C** | interior de gabinete |
| Tj objetivo (semiconductores) | T_j | **≤ 125 °C** | derate desde 175 °C |

### Impedancias base (para pu)

```
Z_base = V_LL² / S              = 400² / 15000        = 10.67 Ω
L_base = Z_base / (2π·f_g)      = 10.67 / 376.99      = 28.3 mH
C_base = 1 / (2π·f_g·Z_base)    = 1 / 4021            = 248.7 µF
```

---

## 2. Arquitectura de control (quién manda a quién)

```
                 ┌─────────────────────── STM32G474 (dominio control) ───────────────────────┐
                 │                                                                            │
  Red ─► AFE  ───┤  PLL trifásico (SRF/DSOGI) ─► θ_grid                                        │
                 │  Lazo Vdc (PI, ~1 kHz) ─► Id*        Lazo corriente dq (PI, 16 kHz) ─► SVPWM├─► gate AFE
                 │  Iq* = 0 (FP unitario) / cmd FP                                             │
                 │                                                                            │
  Motor ◄─ INV ──┤  Encoder/observador ─► θ_rotor                                              │
                 │  Lazo velocidad (PI, ~1 kHz) ─► Iq*  Lazo corriente dq (FOC, 16 kHz) ─►SVPWM├─► gate INV
                 │  Id* = 0 (o field weakening)                                                │
                 │                                                                            │
                 │  Máquina de estados · Protecciones HW (BKIN) · ADC sinc. con PWM            │
                 └───────────────┬───────────────────────────────────────────┬────────────────┘
                                 │ UART/SPI AISLADO (telemetría + setpoints no críticos)      │
                 ┌───────────────┴───────────────┐                                            │
                 │  ESP32 (dominio IoT)          │                                            │
                 │  Modbus TCP · MQTT/TLS · OTA  │──► Node-RED (dashboard mant. predictivo)   │
                 └──────────────────────────────┘
```

**Regla de oro:** el ESP32 **nunca** está en un lazo de par/seguridad. Solo lee
telemetría y propone setpoints que el STM32 **valida, limita y puede ignorar**.

---

## 3. Secuencia de desarrollo (orden de ejecución)

| # | Fase | Entregable | Bloqueante para |
|---|---|---|---|
| 1 | **Dimensionamiento y arquitectura de potencia** (`01_...md`) | LCL, banco C_dc, precarga, semiconductores, térmico | todo |
| 2 | **Esquemático y acondicionamiento** (`02_...md`) | Gate drivers, cadena analógica, aislamiento comms | PCB |
| 3 | **Ruteo de PCB y normativas** (`03_...md`) | Stackup, net classes, creepage/clearance, reglas DRC (`kicad/`) | fabricación |
| 4 | **Firmware de control STM32** (`04_...md`) | Timers/SVPWM/dead-time, ADC sinc., FOC + PLL/AFE | bring-up lazo cerrado |
| 5 | **Telemetría IoT y SCADA ESP32** (`05_...md`) | Protocolo STM32↔ESP32, Modbus/MQTT, Node-RED | puesta en servicio |
| 6 | **Protocolo de pruebas y seguridad** (`06_...md`) | Bring-up escalonado, fuentes limitadas, validación lazo abierto | operación |

Regla práctica: **Fases 1–3 en serie. Fase 4 puede arrancar en paralelo a la 3
usando una Nucleo/Discovery. Fase 5 en paralelo a la 4. Fase 6 solo cuando 1–4
estén cerradas y la placa fabricada y poblada por secciones.**

---

## 4. Estructura del proyecto KiCad

### 4.1 Esquemático jerárquico

```
b2b_converter.kicad_sch                 (raíz: interconexión de hojas, net classes)
├── sch/ac_input_lcl.kicad_sch          entrada AC, fusibles, contactor, LCL, snubber
├── sch/afe_bridge.kicad_sch            6× SiC + Kelvin, decoupling de lazo de conmutación
├── sch/dclink_precharge.kicad_sch      banco C_dc, R de balance, precarga (R + contactor), bleeder, chopper
├── sch/inverter_bridge.kicad_sch       6× SiC + Kelvin, decoupling
├── sch/gate_driver.kicad_sch           ← SUBHOJA REUTILIZABLE, instanciada 6× (o 2× por 3 canales)
├── sch/sense_iv.kicad_sch              sensores Hall / amp. aislados I y V, filtros anti-alias
├── sch/mcu_stm32.kicad_sch             STM32G474, cristal, SWD, refs de ADC
├── sch/protection_io.kicad_sch         comparadores OV/OC, lógica BKIN, relés, e-stop, watchdog
├── sch/psu_aux.kicad_sch               SMPS auxiliar (flyback desde bus o desde 24 V), bias aislados de gate
├── sch/isolation_comms.kicad_sch       aisladores digitales UART/SPI, DC-DC aislado isla ESP32
└── sch/esp32_iot.kicad_sch            ESP32-S3, PHY Ethernet opcional, conectores de campo
```

- La subhoja `gate_driver.kicad_sch` se instancia 6 veces con parámetros de
  hoja distintos (nombre de red de gate, de fuente Kelvin, de bias). Un solo
  archivo a mantener.
- Cada hoja lleva su **rótulo de tensión de trabajo** en la carátula.

### 4.2 Net classes (ver `kicad/netclasses.md` y `kicad/drc_custom_rules.txt`)

| Net class | Nets | Tensión trabajo | Ancho mín. pista |
|---|---|---|---|
| `HV_DC` | DC+, DC-, nodos de fase de puente | 800 V DC | por térmico (≥ 2.5 mm en 2 oz) |
| `HV_AC` | L1/L2/L3 red, salidas motor U/V/W | 566 V pk | idem |
| `GATE_HS` | rieles de gate flotantes (alto lado) | 800 V (referido a PGND) | 0.4 mm |
| `GATE_LS` | gate lado bajo | 30 V | 0.4 mm |
| `CTRL` | 3V3 digital STM32 | 3.3 V | 0.2 mm |
| `ANA` | señales de sensores, refs ADC | ±10 V | 0.25 mm, guardadas |
| `IO_ISO` | dominio ESP32 (aislado) | 3.3 V | 0.2 mm |
| `PE` | tierra de protección / chasis | — | ancha, stitching |

### 4.3 Stackup (mínimo recomendado: 4 capas)

| Capa | Uso | Cobre |
|---|---|---|
| L1 (top) | señales de potencia, DC+ (laminado con L4 en zona de puente), gate loops | 70 µm (2 oz) |
| L2 | **PGND** sólido bajo la zona de potencia; AGND sólido bajo la zona analógica (misma capa, un solo net-tie) | 35 µm |
| L3 | plano de alimentación (3V3, 15 V, bias) + islas | 35 µm |
| L4 (bottom) | DC-, retorno de conmutación (laminado con L1), señales de control, plano DGND bajo el MCU | 70 µm (2 oz) |

Para EMI más exigente o mayor densidad: 6 capas (Sig / GND / Pwr / GND / Sig / Sig).

---

## 5. Lista de estándares aplicables

| Estándar | Aplicación en este proyecto |
|---|---|
| **IEC 61800-5-1** | Seguridad de accionamientos (PDS): aislamiento, distancias, descarga del bus (<60 V en 60 s), ensayos dieléctricos |
| **IEC 60664-1** | Coordinación de aislamiento: clearance/creepage vs. tensión, categoría de sobretensión, grado de polución |
| **IPC-2221B** | Tabla 6-1: espaciamientos eléctricos en PCB por tensión (interno/externo, con/sin recubrimiento) |
| **IPC-2152** | Ampacidad de pistas vs. temperatura y sección de cobre |
| **IEEE 519 / IEC 61000-3-2/-3-12** | Límites de armónicos de corriente inyectados a la red (objetivo del filtro LCL y del control del AFE): **THD_i < 5 %** |
| **IEC 61000-6-2 / -6-4** | Inmunidad y emisión EMC en entorno industrial |
| **CISPR 11 / EN 55011** | Emisiones conducidas y radiadas del equipo |

---

## 6. Cómo usar este repositorio

```
docs/
  00_MASTER_PLAN.md          ← estás aquí
  01_potencia_dimensionamiento.md
  02_esquematico_acondicionamiento.md
  03_pcb_ruteo_normativas.md
  04_firmware_control_stm32.md
  05_telemetria_iot_scada.md
  06_bringup_pruebas_seguridad.md
kicad/
  netclasses.md              ← definición de net classes y anchos
  drc_custom_rules.txt       ← reglas custom de KiCad 8 (clearance + creepage)
  stackup.md                 ← detalle del apilado y control de impedancia
```

Cada archivo de fase termina con una **checklist de salida**: no pases a la
siguiente fase hasta marcarla completa.

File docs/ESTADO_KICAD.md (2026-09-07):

# Estado del proyecto KiCad — qué está hecho y qué falta

> Generado por scripts. Todo se reconstruye con **un comando**:
> `.\tools\build_all.ps1`

---

## 1. Cómo está construido

El esquemático **no** se dibujó a mano: lo genera `tools/gen_schematic.py`,
que **parsea las librerías de símbolos reales de tu KiCad 9** y copia las
definiciones oficiales dentro de cada `.kicad_sch`. Por eso las posiciones de
pin son exactas y los gráficos son los de la librería estándar.

```
tools/
  kisch.py          parser/serializador de s-expresiones + constructor de esquemas
                    + validador símbolo↔footprint (pines vs pads)
  gen_schematic.py  el DISEÑO: 11 hojas, 227 componentes, todas las conexiones
  check_conn.py     verificador propio: extremos de cable sueltos y solapes
                    (los solapes colineales son cortocircuitos silenciosos que
                     el ERC no nombra de forma clara)
  gen_pcb.py        construye la PCB con la API pcbnew: footprints, redes,
                    contorno, zonas de cobre, keepout de barrera
  build_all.ps1     cadena completa
```

Toolchain detectada: **KiCad 9.0.2**, Python 3.11.5 embebido, `kicad-cli`.

---

## 2. Qué existe ahora

### Esquemático — `kicad/b2b_converter.kicad_sch` + `kicad/sch/*`

| Hoja | Componentes | Contenido real capturado |
|---|---:|---|
| 01 Entrada AC + LCL | 26 | Bornera 3~+PE, 3 fusibles, choke CM, LCL completo (L2 0.6 mH · Cf 10 µF · Rd 2.2 Ω · L1 1.5 mH), banco MOV, X/Y caps |
| 02 Puente AFE | 9 | 6× SiC `C3M0075120K` (TO-247-**4**, con pin Kelvin) + 3 condensadores de lazo 1 µF/1 kV |
| 03 Bus DC | 18 | 4× 150 µF/900 V, precarga 68 Ω + bypass, bleeder + LED "BUS LIVE", divisor de 1 MΩ, chopper de frenado + diodo + bornera |
| 04 Puente inversor | 12 | 6× SiC, decoupling, bornera de motor U/V/W/PE, 2 NTC |
| 05 Gate drivers | 54 | **6× `UCC21520DW`** aislados, Rg_on 10 Ω / Rg_off 3.3 Ω con diodo por canal, resistencia de dead-time, desacoplos |
| 06 Sensado I/V | 41 | 6 cadenas de corriente (Hall → burden 0.1 % → anti-alias RC de 2 polos), buffer de Vdc con LM358, referencia de ADC, divisores de NTC |
| 07 STM32 | 20 | `STM32G474VET6` LQFP-100 con mapa de pines completo (TIM1/TIM8, ADC, BKIN, encoder, UART aislado), cristal, SWD, **NT1/NT2 net-ties de tierra** |
| 08 Protección | 17 | 4 comparadores `LM339` → `FAULT_N`, drivers de bobina K1/K2/ventilador con flyback, e-stop, LEDs |
| 09 Aux + bias | 15 | Entrada 24 V protegida, 3 reguladores, **6 módulos DC-DC aislados** para bias de gate, banco de `PWR_FLAG` |
| 10 Aislamiento | 3 | `ADuM1401` reforzado: UART + heartbeat, desacoplos a ambos lados |
| 11 ESP32 | 11 | `ESP32-S3-WROOM-1`, botones EN/BOOT, LEDs, conector de campo |

**227 componentes · 130 redes.** Las hojas se conectan por *global labels*.

### PCB — `kicad/b2b_converter.kicad_pcb`

- **340 × 240 mm, 4 capas.** 227 footprints colocados, 130 redes asignadas.
- Floorplan con flujo de energía izquierda→derecha:
  `01 LCL → 02 AFE → 03 BUS DC → 04 INVERSOR → motor`.
- **Barrera de aislamiento** como `Rule Area` llamada `ISO_BARRIER` (franja de
  6 mm sin cobre en las 4 capas). Los 6 gate drivers están colocados **a
  caballo** de ella — la barrera atraviesa el encapsulado, que es lo correcto.
- Zonas de cobre rellenadas: `DC_P` (F.Cu) y `DC_N` (B.Cu) **solapadas** sobre
  el banco → bus laminado; `PGND` en In1 sobre la zona HV; `GND` en In1/In2/B
  sobre la zona LV; **`IOGND` como isla aparte** para el ESP32.
- Colocación explícita de la etapa de potencia: los 12 SiC en dos filas
  alineadas al borde del disipador, banco DC en 2×2 en el centro.
- 6 agujeros M4, contorno, serigrafía con rótulos de zona y el aviso de HV.

### Salidas

```
export/b2b_esquematicos.pdf    los 12 planos (raíz + 11 hojas)
export/svg/*.svg               una hoja por archivo
export/erc.rpt, drc.rpt        informes
render/b2b_top.png             render 3D cenital
render/b2b_iso.png             render 3D en perspectiva
render/b2b_bottom.png          cara inferior
```

---

## 3. Qué FALTA (honestamente)

| Pendiente | Estado | Comentario |
|---|---|---|
| **Ruteo de pistas** | **0 %** | 326 `unconnected_items` en DRC. Es lo esperado: no hay ni una pista. Se rutea en Pcbnew siguiendo `docs/KICAD_PCB_FLOORPLAN.md` §5 |
| `items_not_allowed` (81) | pendiente | Pads que aún caen dentro de `ISO_BARRIER`. Ajustar posición fina de los drivers |
| `courtyards_overlap` (30) | pendiente | Colocación automática demasiado densa en algunas zonas |
| `solder_mask_bridge` (12) | pendiente | Deriva de lo anterior |
| Avisos de serigrafía (398) | cosmético | Texto de referencia sobre cobre/solapado |
| `endpoint_off_grid` (~1050) | cosmético | Los pines conectan **exactos**; solo no caen en múltiplos de 1.27 mm. Se prioriza conectividad correcta sobre la rejilla |
| Símbolos de fabricante | parcial | Se usan piezas reales de la librería estándar. Para producción hay que sustituir los genéricos (Hall, DC-DC aislados, reguladores) por los del fabricante |
| Verificación de creepage con footprints reales | pendiente | Las reglas están en `kicad/drc_custom_rules.txt`; hay que cargarlas en Board Setup y medir en los puntos peores |

### Nota de ingeniería sobre el MOSFET

La librería trae `C3M0075120K` (1200 V, **75 mΩ**). Con esa pieza a 15 kVA:

```
P_cond = 13.9² × (75 mΩ × 1.5) ≈ 21.7 W  →  ~25 W/dispositivo con conmutación
12 dispositivos ≈ 300 W  →  Rth_s-a ≤ 0.19 °C/W  (exige buen aire forzado)
```

Para el build real usa el **`C3M0040120K` (40 mΩ)**: mismo TO-247-4, mismos
pines, ~15 W/dispositivo y `Rth_s-a ≤ 0.37 °C/W`. Solo hay que cambiar el
campo *Value* — el símbolo y el footprint no cambian.

---

## 4. Siguiente paso recomendado

1. Abre `kicad/b2b_converter.kicad_pro` en KiCad 9 y revisa los planos.
2. Board Setup → **Custom Rules** → pega `kicad/drc_custom_rules.txt`.
3. Rutea por bloques en el orden de `docs/KICAD_PCB_FLOORPLAN.md` §5, empezando
   por los **lazos de conmutación** (lo que fija el EMI de toda la placa).
4. Cualquier cambio de diseño hazlo en `tools/gen_schematic.py` y re-ejecuta
   `build_all.ps1` — así el esquemático y la PCB no se desincronizan.

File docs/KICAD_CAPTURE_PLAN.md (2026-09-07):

# Plan de Captura del Esquemático — sheet por sheet

> Objetivo: convertir la captura del esquemático en **entrada de datos**, no en
> diseño. Cada sheet lista *refdes → valor → footprint → símbolo KiCad → conexiones*.
> Abre `kicad/b2b_converter.kicad_pro` en KiCad 8, entra a cada subhoja y coloca.
>
> Cálculos y justificación numérica: `docs/01_potencia_dimensionamiento.md`.
> Punto de diseño ancla: **15 kVA · 400 V_LL · 60 Hz · V_dc ≤ 800 V · f_sw 16 kHz**.

---

## Convenciones de nets globales (etiquetas jerárquicas)

| Net | Clase | Dominio | Descripción |
|---|---|---|---|
| `GRID_L1/L2/L3` | HV_AC | potencia | fases de red tras fusible+contactor |
| `LCL_A/B/C` | HV_AC | potencia | nodo intermedio LCL (entre L1conv y Cf) |
| `SW_A/B/C` | HV_DC | potencia | nodos de conmutación AFE |
| `SW_U/V/W` | HV_DC | potencia | nodos de conmutación inversor |
| `MOT_U/V/W` | HV_AC | potencia | salida a motor tras choke |
| `DC_P` / `DC_N` | HV_DC | potencia | bus DC + / − |
| `DC_MID` | HV_DC | potencia | punto medio del banco (solo opción electrolítica) |
| `G_H1..6` `G_L1..6` | GATE_HS/LS | gate | gate alto/bajo de cada rama (1–3 AFE, 4–6 INV) |
| `KELVIN_H1..6` `KELVIN_L1..6` | GATE_HS/LS | gate | retorno Kelvin source |
| `PWM_H1..6` `PWM_L1..6` | CTRL | control | PWM lógicos desde STM32 |
| `FLT_1..6` | CTRL | control | fallo DESAT aislado por rama |
| `AIN_IAFE_A/B/C` `AIN_IMOT_U/V/W` | ANA | control | corrientes acondicionadas a ADC |
| `AIN_VDC` `AIN_VGRID_A/B/C` `AIN_VMOT_*` | ANA | control | tensiones acondicionadas a ADC |
| `AIN_NTC1/2` | ANA | control | termistores disipador/módulo |
| `VREF_ADC` | ANA | control | referencia buffered del ADC (3.000 V) |
| `/FAULT` | CTRL | control | línea de fallo agregada → BKIN |
| `EN_PWR` | CTRL | control | habilitación global de PWM |
| `K1_DRV` `K2_DRV` `FAN_DRV` | Default | control | mando de bobinas (low-side) |
| `ISO_UART_TX/RX` `ISO_HB_A/B` | CTRL↔IO_ISO | barrera | enlace STM32↔ESP32 aislado |
| `+15V` `+5V` `+3V3` `+3V3_ANA` `-15V` | Default/ANA | aux | rieles |
| `+15Vg1..6` `-4Vg1..6` `GNDg1..6` | flotante | gate | bias aislado por rama |
| `PE` | PE | — | tierra de protección / chasis |

**Reglas ERC que vas a activar** (Schematic Setup → Electrical Rules):
- Pin analógico de entrada del ADC = `passive`/`input`; marca `no-connect` explícito en todo pin no usado.
- Etiqueta jerárquica sin par en la raíz = error (para no dejar nets colgadas entre hojas).

---

## SHEET 01 — Entrada AC + Filtro LCL  (`sch/ac_input_lcl.kicad_sch`)

### Cálculo del LCL (resumen; detalle en 01_potencia_dimensionamiento.md)

```
I_n      = S / (√3·V_LL)              = 15000/(1.732·400)      = 21.65 A RMS
Z_base   = V_LL²/S                    = 10.67 Ω
L_base   = Z_base/(2π·60)             = 28.3 mH
C_base   = 1/(2π·60·Z_base)           = 248.7 µF

L1_conv  = V_dc/(8·ΔI_pp·f_sw)  con ΔI_pp = 0.15·I_pk = 4.6 A
         = 700/(8·4.6·16000)         ≈ 1.5 mH   (0.053 pu, dentro de 3–8 %)

Cf       = 0.04·C_base ≈ 10 µF (Y)   → Q_reactiva ≈ 4 % de S   (límite típico 5 %)

L2_grid: se fija ubicando la resonancia. Objetivo f_res ≈ 2.4 kHz:
   f_res = (1/2π)·√[(L1+L2)/(L1·L2·Cf)]
   con L1 = 1.5 mH, Cf = 10 µF, f_res = 2400 Hz  →  L2 ≈ 0.6 mH  (r = L2/L1 = 0.4)
   Restricción:  10·f_g (600 Hz)  <  f_res  <  0.5·f_sw (8000 Hz)   ✔

Atenuación de rizado a f_sw (grid vs. conv):
   k_a = 1/|1 − ω_sw²·L1·Cf·(1+r)/r ...|  ≈ 0.02   → grid ripple ≈ 2 % del de convertidor  ✔

Amortiguamiento (R serie con Cf):
   R_d = 1/(3·ω_res·Cf) = 1/(3·2π·2400·10e-6) ≈ 2.2 Ω     (empezar 2.2 Ω / 10 W, optimizar)
```

### Componentes

| Ref | Valor | Footprint | Símbolo KiCad | Notas |
|---|---|---|---|---|
| J1 | Bornera 4 vías 800 V/32 A | `TerminalBlock:TerminalBlock_Phoenix_...5.08mm` | `Connector:Screw_Terminal_01x04` | L1,L2,L3,PE |
| F1–F3 | Fusible 25 A aR/gG | `Fuse:Fuse_Bel_0ADAC` o portafusible DIN externo | `Device:Fuse` | uno por fase |
| RV1–RV3 | MOV 20D471K (300 VAC/470 V clamp) | `RV_Disc_D20mm_W5.0mm_P10mm` | `Device:Varistor` | fase-fase o fase-PE, clase II |
| K1 | Contactor 3P 25 A, bobina 24 VDC | huella de relé de potencia o bornas a contactor externo | `Relay:...` o `Connector` | mando `K1_DRV` desde sheet 08 |
| L_CM1 | Choke modo común 3~ 3–5 mH | huella toroide / módulo | `Device:L` (x3 acoplados) o símbolo choke 3ph | filtro EMC de entrada |
| CX1–CX2 | 0.47 µF X2 275 VAC | `C_Rect_L26.0mm_W6.0mm_P22.50mm_...` | `Device:C` | modo diferencial |
| CY1–CY3 | 4.7 nF Y2 | `C_Disc_D9.0mm_...` | `Device:C` | a `PE` |
| L1A/L1B/L1C | **1.5 mH** / 30 A / núcleo de polvo o ferrita con gap | huella de inductor de potencia bobinado / bornas a inductor externo | `Device:L` | lado convertidor (uno por fase) |
| CFA/CFB/CFC | **10 µF** film 3~ (o 3× monofásico) 500 VAC | `C_Rect_...P37.5mm` | `Device:C` | conexión Y, punto común flotante o a `PE` según diseño |
| RDA/RDB/RDC | **2.2 Ω / 10 W** | `R_Axial_Power_L25.0mm...` | `Device:R` | serie con cada Cf (damping pasivo) |
| L2A/L2B/L2C | **0.6 mH** / 30 A | huella inductor / bornas | `Device:L` | lado red (uno por fase) |
| TP1–TP6 | test points | `TestPoint:TestPoint_Pad_D2.0mm` | `Connector:TestPoint` | GRID_Lx y LCL_x para scope diferencial |

### Conexiones

```
J1.L1 ─ F1 ─ K1.A1 ── GRID_L1 ── L_CM1 ── L1A ── LCL_A ── (RDA+CFA a nodo Y) ── L2A ── SW_A?  NO:
```
Ojo al orden físico del LCL: **red → L2_grid → (Cf+Rd al centro) → L1_conv → puente**.
Corrige así:

```
J1.L1 ─F1─ K1 ── GRID_L1 ─ L_CM1 ─ L2A ─ LCL_A ─┬─ L1A ─ SW_A (a sheet 02, gate del medio-puente A)
                                                 └─ RDA ─ CFA ─ NODO_Y
(idéntico para B, C ; NODO_Y común de los tres Cf; conectar NODO_Y a PE por 1 punto o dejar flotante)
J1.PE ── PE  (barra de tierra, a chasis por espárrago)
```
Etiquetas jerárquicas de salida: `SW_A/B/C` **no** — el nodo que va al puente es
la corriente de línea del AFE; nómbralo `AFE_A/B/C` para no confundir con el nodo
de conmutación interno del puente. Ajusta: **salida de sheet 01 = `AFE_A/B/C`**.
Sensado: deriva `AIN_VGRID_A/B/C` desde `GRID_Lx` (a sheet 06) y coloca 3
transductores de corriente sobre `AFE_A/B/C` → `AIN_IAFE_A/B/C`.

---

## SHEET 02 — Puente AFE  (`sch/afe_bridge.kicad_sch`)

### Selección de interruptor (resumen; detalle en 01_...md §3)

| | IGBT 1200 V | **SiC MOSFET 1200 V** ← elegido |
|---|---|---|
| f_sw práctica | 8–12 kHz | 16–48 kHz |
| Pérdida conmutación | alta (cola) | baja |
| Tamaño LCL / magnéticos | mayor | menor |
| Coste | menor | mayor |
| Recomendación 15 kW regenerativo | — | **SiC discreto TO-247-4** |

```
Conducción por MOSFET (inversor, aprox):
   I_S,rms ≈ I_ph,pk·√(1/8 + m·cosφ/(3π)) = 30.6·√(0.125+0.081) ≈ 13.9 A
   R_dson(125°C) ≈ 1.5·40 mΩ = 60 mΩ
   P_cond ≈ 13.9²·0.060 ≈ 11.6 W  por dispositivo

Conmutación:  E_on+E_off ≈ 0.13 mJ @ 700 V / 15 A (escalado de datasheet)
   P_sw ≈ 0.13e-3·16000 ≈ 2.1 W ;  + Qrr cuerpo ≈ 1 W  →  ≈ 3 W

Total ≈ 15 W/dispositivo · 12 = 180 W semis.  η global ≈ 97–98 %.
```

### Componentes (rama tipo, ×3: A, B, C — refdes Q1..Q6)

| Ref | Valor | Footprint | Símbolo | Notas |
|---|---|---|---|---|
| Q1,Q3,Q5 | SiC MOSFET 1200 V / 40 mΩ (alto) | `Package_TO_SOT_THT:TO-247-4_...` (pin Kelvin) | `Transistor_FET:...` genérico N-MOS 4pin o símbolo propio | drain→`DC_P` |
| Q2,Q4,Q6 | SiC MOSFET 1200 V / 40 mΩ (bajo) | idem | idem | source→`DC_N` (vía Kelvin sense aparte) |
| Cdec1_A..C | 1 µF / 1 kV C0G o film | `C_Rect_L18...` o `C_1210_...` (varios en //) | `Device:C` | **DC_P–DC_N pegado a cada rama, < 10 mm** |
| Rsn_A..C + Csn_A..C | 10 Ω 2 W + 1 nF 1 kV | `R_Axial...` + `C_Disc...` | `Device:R`,`Device:C` | snubber RC opcional drain-source lado bajo (poblar tras bench) |
| Rg no aquí | — | — | — | los Rg viven en sheet 05 (junto al driver) |
| TP_SWA..C | — | `TestPoint` | — | nodo de conmutación para scope dv/dt |

### Conexiones por rama A (repetir B con Q3/Q4/SW_B, C con Q5/Q6/SW_C)

```
DC_P ─┬─ Q1.D
      └─ Cdec1_A ─ DC_N
Q1.S ─┬─ Q2.D ─── SW_A ─── (a sheet 01: nodo AFE_A, tras L1A)
      └─ (KELVIN_H1 al sheet 05, sense de source alto)
Q2.S ─┬─ DC_N
      └─ (KELVIN_L1 al sheet 05)
Q1.G ── G_H1 (sheet 05)      Q2.G ── G_L1 (sheet 05)
Transductor de corriente sobre SW_A o sobre AFE_A → AIN_IAFE_A (sheet 06)
```

> **Regla de layout que ya condiciona la captura:** agrupa `Q1,Q2,Cdec1_A` como
> bloque; el par `DC_P/DC_N` entra por un lado y sale `SW_A` por el opuesto. En
> PCB esto es el *lazo de conmutación* — objetivo < 20 nH.

---

## SHEET 03 — Bus DC + Precarga + Chopper  (`sch/dclink_precharge.kicad_sch`)

### Cálculo (detalle en 01_...md §2)

```
Rizado de corriente del capacitor (inversor, peor caso):
   I_C,rms ≈ 0.55·I_o,rms ≈ 0.55·21.65 ≈ 12 A RMS @ f_sw + baja frecuencia
   → banco debe soportar ≥ 15–20 A RMS de rizado

Capacitancia por transitorio de frenado (700 V → 780 V antes del chopper,
   tiempo de respuesta del lazo de bus ≈ 1.5 ms a 15 kW regen):
   E = P·t = 15000·1.5e-3 = 22.5 J
   ½·C·(780² − 700²) = 22.5  →  C ≈ 380 µF   (mínimo)

Elección:  C_bus objetivo 470–700 µF.
   OPCIÓN A (film, recomendada SiC):  4× 150 µF / 900 Vdc = 600 µF, sin balanceo, ESL baja
   OPCIÓN B (electrolítico):  2S3P de 470 µF/450 V ≈ 705 µF ; R_balance por cap:
        I_bal = 10 mA → R = 400 V / 0.01 = 40 kΩ → usar 33 kΩ / 5 W
        τ_descarga = 33k·470µF = 15.5 s → <60 V en ~2τ ≈ 31 s  ✔ (IEC 61800-5-1)
   + 2× 2.2 µF / 1 kV film para HF sea cual sea la opción.

Precarga (soft-start):
   V_pk_natural = √2·400 = 566 V (a través de diodos de cuerpo del AFE)
   I_inrush ≤ 8 A  →  R_pc = 566 / 8 = 70.75 Ω  →  68 Ω
   τ = R_pc·C_bus = 68·700e-6 = 47.6 ms ;  95 % en 3τ ≈ 143 ms ;  99 % en 5τ ≈ 238 ms
   Energía en R_pc por carga = ½·C·V_pk² = ½·700e-6·566² ≈ 112 J
   Pico de potencia = 566²/68 ≈ 4.7 kW (instantáneo, decae con τ)
   → resistencia bobinada con rating de pulso ≥ 3·112 J y térmico repetitivo.
   Cierre de K2 (bypass) a V_dc ≥ 510 V  o  t = 300 ms  (lo que ocurra primero);
   FALLO si V_dc no sube en 1 s (cap en corto)  o  sube demasiado lento (K2 abierto / ESR alta).

Chopper de frenado (respaldo):  umbral 760–780 V ;  R_brk externa dimensionada por
   potencia de frenado media requerida (bornera + disipador propio).
```

### Componentes

| Ref | Valor | Footprint | Símbolo | Notas |
|---|---|---|---|---|
| C1–C4 (opc. A) | 150 µF / 900 Vdc film DC-link | `Capacitor_THT:CP_Radial_...` grande / bornas | `Device:C_Polarized` o `Device:C` | `DC_P`–`DC_N` |
| C1–C6 (opc. B) | 470 µF / 450 V snap-in | `CP_Radial_D35.0mm_P10.00mm` | `Device:C_Polarized` | 2 en serie (`DC_P`–`DC_MID`–`DC_N`) ×3 ramas |
| Rb1–Rb6 (opc. B) | 33 kΩ / 5 W | `R_Axial_Power_L38...` | `Device:R` | 1 por cap, balanceo |
| C5,C6 | 2.2 µF / 1 kV film | `C_Rect_L26...` | `Device:C` | decoupling HF del bus |
| Rpc | 68 Ω / pulso ≥ 350 J (2×33 Ω 100 W en serie) | bornas a resistencia externa | `Device:R` | precarga |
| K2 | Contactor/relé 1P 20 A 24 VDC | relé de potencia o bornas | `Relay:...` | bypass de Rpc, mando `K2_DRV` |
| Rbleed | 100 kΩ / 3 W (o bleeder activo) | `R_Axial_Power_L38...` | `Device:R` | descarga permanente + LED |
| D_bleed_LED + R | LED rojo + 220 kΩ | — | `Device:LED`,`Device:R` | indicador "BUS LIVE" |
| Qbrk | SiC/IGBT 1200 V ≥ 30 A | `TO-247-3` | `Transistor_FET`/`IGBT` | chopper |
| Dbrk | diodo SiC 1200 V ≥ 30 A | `TO-247-2` | `Device:D` | free-wheel de R_brk |
| Jbrk | bornera 2 vías | `Screw_Terminal_01x02` | `Connector` | a resistencia de frenado externa |
| Rsh_dc / div | divisor 5×200 kΩ 0.1 % | `R_1206` ×5 en serie | `Device:R` | a amp aislado (sheet 06): `AIN_VDC` |

### Conexiones

```
(desde sheet 02 diodos de cuerpo) rectificado ── Rpc ──┬── DC_P (banco)
K2 en paralelo con Rpc (bypass)                          │
                                        C1..Cn ═════════ DC_P / DC_N
Qbrk.D ── DC_P ;  Qbrk.S ── Jbrk.1 ;  Jbrk.2 ── DC_N ;  Dbrk entre Jbrk.1 y DC_P
Rbleed entre DC_P y DC_N (siempre) ;  LED "BUS LIVE" en serie con su R
Divisor DC_P→...→DC_N, toma media a sheet 06
DC_P / DC_N como etiquetas jerárquicas hacia sheet 02 y sheet 04 (bus laminado en PCB)
Gate de Qbrk ← PWM_BRK (sheet 07)  con su propio driver simple (puede ir en sheet 05 como 7ª instancia reducida)
```

---

## SHEET 04 — Puente Inversor  (`sch/inverter_bridge.kicad_sch`)

Idéntico a **SHEET 02** en topología y componentes, con:

| Rama | Alto | Bajo | Nodo | Gate | Corriente |
|---|---|---|---|---|---|
| U | Q7 | Q8 | `SW_U` | `G_H4`/`G_L4` | `AIN_IMOT_U` |
| V | Q9 | Q10 | `SW_V` | `G_H5`/`G_L5` | `AIN_IMOT_V` |
| W | Q11 | Q12 | `SW_W` | `G_H6`/`G_L6` | `AIN_IMOT_W` |

Añadidos propios del lado motor:

| Ref | Valor | Footprint | Símbolo | Notas |
|---|---|---|---|---|
| L_CM2 | choke modo común de salida 3~ (opcional) | toroide / módulo | choke 3ph | reduce corriente de fuga por cable de motor |
| Rcl+Ccl (×3) | clamp dv/dt de cable (RC) | `R_Axial`,`C_Disc` | `Device:R/C` | poblar según largo de cable |
| J_MOT | bornera 4 vías (U,V,W,PE) | `Screw_Terminal_01x04` grande | `Connector` | 360° shield clamp del cable |
| RT1,RT2 | NTC 10 kΩ B3950 | `R_Axial` / cable | `Device:Thermistor` | 1 en disipador, 1 en módulo → `AIN_NTC1/2` (sheet 06) |

```
DC_P/DC_N (de sheet 03) ═══ ramas Q7..Q12 ═══
SW_U/V/W ── L_CM2 ── (Rcl/Ccl) ── MOT_U/V/W ── J_MOT
J_MOT.PE ── PE
```

---

## SHEET 05 — Gate Driver aislado (instancia ×6)  (`sch/gate_driver.kicad_sch`)

### Diseño (detalle en 02_esquematico_acondicionamiento.md §1)

- **Aislador**: driver reforzado con CMTI > 100 V/ns, DESAT y CLAMP integrados.
  Candidatos: `UCC21750` (TI), `STGAP2S`/`STGAP3S` (ST, encaja con ecosistema STM32),
  `1EDI3021AS` (Infineon).
- **Bias por lado**: +15 V / −4 V. Generación: `SN6505B` + transformador push-pull
  + rectificador + LDO, **o** módulo (`MGJ2D152005`, `RP-1515D`...). 2 W por lado.
- **Rg**: `Rg_on ≈ 10 Ω`, `Rg_off ≈ 3.3 Ω` (separados con diodo de conmutación).
  Empezar ahí, ajustar en bench midiendo dv/dt y sobreimpulso Vgs.
- **Active Miller Clamp**: pin CLAMP → gate, traza < 10 mm, activa cuando Vgs < 2 V.
- **DESAT**: diodo(s) serie HV (`US1M`/`STTH1L06` ×2) a VDS, `C_blank ≈ 330 pF`
  (→ t_blank ≈ 1–2 µs), umbral ~7–9 V. Falla → turn-off suave (STO) + `FLT` latcheado.
- **Kelvin source** del 4º pin del SiC directo al pin de referencia del driver.
- Clamp gate-source: TVS/Zener `+20 / −6 V`. Decoupling `100 nF + 1 µF` en el driver
  y otro `100 nF + 1 µF` junto al SiC.

### Componentes por instancia (parámetros de hoja: `n` = 1..6)

| Ref | Valor | Footprint | Símbolo | Conecta |
|---|---|---|---|---|
| U_GDn | driver aislado reforzado | `Package_SO:SOIC-16W_...` (según parte) | símbolo del fabricante | ver abajo |
| U_BIASn | módulo DC-DC aislado 15/−4 V 2 W | huella del módulo | `Converter_DCDC:...` | `+15V`/`GND` in, `+15Vgn`/`-4Vgn`/`GNDgn` out |
| Rg_on_Hn / Rg_on_Ln | 10 Ω 1 W | `R_2512` | `Device:R` | driver OUT_H → `G_Hn` (idem L) |
| Rg_off_Hn / Rg_off_Ln | 3.3 Ω 1 W | `R_2512` | `Device:R` | rama de apagado con `D_off` |
| D_off_Hn/Ln | diodo rápido 200 V | `D_SOD-123` | `Device:D` | paralelo a Rg_on |
| D_desatHn/Ln | 2× `STTH1L06` (600 V) | `D_SMA` | `Device:D` | pin DESAT → `SW_x`/`DC_N` |
| C_blankHn/Ln | 330 pF 100 V | `C_0603` | `Device:C` | pin DESAT → source |
| TVS_gsHn/Ln | `+20/−6 V` | `D_SOD-323` | `Device:D_Zener_Dual` | gate ↔ Kelvin |
| C_bias in/out | 100 nF + 1 µF ×2 lados | `C_0603`,`C_0805` | `Device:C` | VCC/VEE del driver |
| U_isoFLTn (si el driver no lo trae) | 1 ch aislador | `SOT-23-6` | — | `FLT` interno → `FLT_n` (dominio CTRL) |

### Conexiones (por instancia n)

```
Dominio CTRL (izquierda del aislador):
   PWM_Hn ── U_GDn.INA        PWM_Ln ── U_GDn.INB (o driver dual de 1 canal ×2)
   EN_PWR ── U_GDn.EN
   U_GDn.FLT ── FLT_n         (a sheet 08, agregación de fallo)
   +5V / +3V3 ── U_GDn.VCCI   ;  DGND ── U_GDn.GNDI

Barrera (creepage 8 mm en PCB, ranura si el paquete no llega)

Dominio potencia (derecha):
   +15Vgn ── U_GDn.VDD ;  -4Vgn ── U_GDn.VEE ;  GNDgn ── U_GDn.VSS (= KELVIN de esa rama)
   U_GDn.OUT_H ─ Rg_on_Hn ∥ (Rg_off_Hn+D) ─ G_Hn
   U_GDn.CLAMP_H ── G_Hn (traza corta)
   U_GDn.DESAT_H ─ D_desatHn ─ SW_x   (alto: a nodo de conmutación de su rama)
   idem lado bajo con DC_N como referencia de DESAT
```

> Instanciación en KiCad: coloca el sheet `gate_driver.kicad_sch` **6 veces** en
> `05` (o crea `05` como contenedor con 6 sub-sheets del mismo archivo). Usa
> *sheet fields* o etiquetas jerárquicas parametrizadas (`G_H${n}`) — KiCad 8
> no sustituye variables en labels, así que la vía práctica es **6 copias del
> archivo** `gate_driver_1.kicad_sch`..`_6.kicad_sch` con los labels ya numerados,
> o una hoja plana con los 6 bloques. Recomendado: hoja plana `05` con 6 bloques
> (más fácil de revisar el ruteo después).

---

## SHEET 06 — Sensado I/V + AFE analógico  (`sch/sense_iv.kicad_sch`)

### Diseño (detalle en 02_...md §2)

**Corriente (6 canales)** — elige una vía y úsala en todos:
- (a) **Hall closed-loop** (`LEM LA 25-NP`, `LKSR 15-NP`, `HO 25-P`): salida en
  corriente → `R_burden` 0.1 % 25 ppm → ±V. Aislamiento inherente.
- (b) **Sigma-delta aislado** (`AMC1305M25` / `AMC1035`) + shunt Kelvin 1–2 mΩ →
  al `DFSDM`/`ADC-SD` del STM32. Mejor rechazo y precisión, más firmware.

Cadena tras el sensor: amp diferencial / nivel (`OPA2320`, `ADA4522-2` zero-drift
para exactitud DC) → offset a `VREF_ADC/2` (1.5 V) → filtro **Sallen-Key 2º orden
Butterworth**, `f_c ≈ 12–16 kHz`, retardo de grupo < 1 µs.

**Tensión (7 canales: V_dc + 3 red + 3 motor)**:
- Amp aislado de alta impedancia (`AMC1311`, entrada ±2 V) con divisor resistivo,
  o sigma-delta. Divisor de bus: `5× 200 kΩ` (1 MΩ) → 800 V ≈ 1.6 mA, 0.13 W/R,
  usar `1206`/`2010` con rating de tensión.

**Referencia ADC**: `REF5030` (3.000 V) buffered → `VREF_ADC`, en estrella al pin
`VREF+` del STM32, con `10 µF + 100 nF` dedicados. Ratiométrico donde se pueda.

### Componentes (por canal de corriente, ×6; refdes con sufijo de canal)

| Ref | Valor | Footprint | Símbolo | Notas |
|---|---|---|---|---|
| U_Ixx | Hall LA 25-NP (o AMC1305) | huella LEM / `SOIC-16` | fabricante | primario en serie con `AFE_x`/`SW_x` |
| Rb_xx | burden 100 Ω 0.1 % 25 ppm | `R_1206` | `Device:R` | solo Hall |
| U_AIxx | OPA2320 / ADA4522-2 | `SOIC-8` | `Amplifier_Operational:OPA2320` | dif + offset |
| Rf/Ri xx | red de ganancia 0.1 % | `R_0603` | `Device:R` | ganancia a fondo de escala 3.0 V |
| SK filtro | R,R,C,C Butterworth fc≈14 kHz | `R_0603`,`C_0603 C0G` | `Device:R/C` | 2º orden |
| C_aa | 1 nF C0G a la entrada del ADC | `C_0603` | `Device:C` | + `33 Ω` serie |
| Out | — | — | — | `AIN_IAFE_A/B/C`, `AIN_IMOT_U/V/W` |

### Componentes (tensión, por canal ×7)

| Ref | Valor | Footprint | Símbolo | Notas |
|---|---|---|---|---|
| Rdiv_xx (×5) | 200 kΩ 0.1 % | `R_1206` | `Device:R` | cadena serie |
| U_Vxx | AMC1311 | `SOIC-8` | fabricante | entrada ±2 V |
| U_Vbuf_xx | OPA320 | `SOT-23-5` | `Amplifier_Operational` | buffer salida aislador |
| SK filtro | fc≈14 kHz | — | — | igual que corriente |
| Out | — | — | — | `AIN_VDC`, `AIN_VGRID_A/B/C`, `AIN_VMOT_U/V/W` |

| Ref | Valor | Footprint | Símbolo | Notas |
|---|---|---|---|---|
| U_REF | REF5030AIDR | `SOIC-8` | `Reference_Voltage:REF5030` | 3.000 V |
| U_REFBUF | OPA320 | `SOT-23-5` | — | buffer de fuerza |
| C_ref | 10 µF + 100 nF | `C_0805`,`C_0603` | `Device:C` | |
| RT1,RT2 in | 2× NTC (de sheet 04) | — | `Device:Thermistor` | pull-up a +3V3_ANA → `AIN_NTC1/2` |
| NT1 | **Net-tie AGND↔? no aquí** | — | — | el net-tie va en sheet 07 |

### Comparadores de protección (van a sheet 08)

| Señal | Fuente | Umbral | Destino |
|---|---|---|---|
| OC_IAFE_x / OC_IMOT_x | salida de cada Hall (antes del filtro) | 1.8× I_pk ≈ 55 A | ventana → `/FAULT` |
| OV_DC | `AIN_VDC` sin filtrar | 800 V | comparador → `/FAULT` |
| OT | `AIN_NTC1` | equivalente 95 °C | comparador → `/FAULT` |

---

## SHEET 07 — STM32G474  (`sch/mcu_stm32.kicad_sch`)

### Componentes

| Ref | Valor | Footprint | Símbolo | Notas |
|---|---|---|---|---|
| U1 | STM32G474VET6 | `Package_QFP:LQFP-100_14x14mm_P0.5mm` | `MCU_ST_STM32G4:STM32G474VETx` | |
| Y1 | 24 MHz HSE | `Crystal_SMD_3225-4Pin` | `Device:Crystal` | + 2× 18 pF |
| C_vdd | 10× 100 nF + 2× 4.7 µF | `C_0402`/`C_0805` | `Device:C` | 1 por par VDD/VSS |
| C_vcap | 2× 2.2 µF | `C_0603` | `Device:C` | pines VCAP |
| U2 | LDO 3V3 bajo ruido (`TLV75533`) | `SOT-23-5` | `Regulator_Linear` | `+3V3` |
| U3 | LDO 3V3 analógico (`ADM7154`) | `SOT-23` | — | `+3V3_ANA` desde `+5V` |
| FB1 | ferrita 600 Ω | `L_0603` | `Device:FerriteBead` | `+3V3`→`+3V3_ANA` (si no LDO propio) |
| J_SWD | 10 pin Cortex Debug | `PinHeader_2x05_P1.27mm` | `Connector_Generic` | SWD + SWO + NRST |
| NT1 | Net-Tie 2 | `NetTie-2_SMD_Pad0.5mm` | `Device:Net-Tie_2` | **AGND ↔ DGND** bajo VREF− |
| NT2 | Net-Tie 2 | `NetTie-2_SMD_Pad1.0mm` | `Device:Net-Tie_2` | **DGND ↔ PGND** en retorno de DC_N sense |
| SW1 | pulsador NRST | `SW_SPST_...` | `Switch` | |

### Mapa de pines (propuesta — verifícalo en STM32CubeMX contra tu paquete)

| Función | Periférico | Pines (LQFP100) | Net |
|---|---|---|---|
| PWM inversor U/V/W + comp. | TIM1_CH1/1N/2/2N/3/3N | PE9/PE8/PE11/PE10/PE13/PE12 | `PWM_H4..6` / `PWM_L4..6` |
| PWM AFE A/B/C + comp. | TIM8_CH1/1N/2/2N/3/3N | PC6/PA7/PC7/PB0/PC8/PB1 | `PWM_H1..3` / `PWM_L1..3` |
| Trigger ADC (centro PWM) | TIM1_CH4 / TIM8_CH4 | interno | — |
| Break (fallo HW) | TIM1_BKIN / BKIN2, TIM8_BKIN | PA6 / PE15 / PA0 | `/FAULT` (+ redundante) |
| ADC corrientes motor | ADC1_IN / ADC2_IN | PA0.. (elige) | `AIN_IMOT_U/V/W` |
| ADC corrientes red | ADC3/ADC4 | PB.. | `AIN_IAFE_A/B/C` |
| ADC V_dc, V_grid, V_mot, NTC | ADC5 + otros | — | `AIN_VDC`,`AIN_VGRID_*`,`AIN_VMOT_*`,`AIN_NTC1/2` |
| Encoder motor | TIM3_CH1/CH2 | PA6/PA7 (o PB4/PB5) | `ENC_A/ENC_B` (+ `ENC_Z`) |
| Enlace ESP32 | USART2_TX/RX | PA2/PA3 | `ISO_UART_TX/RX` (a sheet 10) |
| Heartbeat | GPIO EXTI | PB12/PB13 | `ISO_HB_A/ISO_HB_B` |
| Mando relés | GPIO | PD.. | `K1_DRV`,`K2_DRV`,`FAN_DRV` (a sheet 08) |
| Watchdog externo | GPIO | PD.. | `WDI` (a sheet 08) |
| Habilitación PWM global | GPIO | PD.. | `EN_PWR` (a sheet 05/08) |
| Chopper | TIM (1 ch) o GPIO+comp | PB.. | `PWM_BRK` |
| VREF+ | — | pin 22 (VREF+) | `VREF_ADC` |

### Reglas de tierra (esto define el ruteo — cierra sheet 07 con esto claro)

```
PGND  = retorno de potencia (DC-link, sources, Cf). Cobre pesado, zona laminada.
AGND  = referencia de sensores, op-amps, VREF. Vertido propio bajo la zona analógica.
DGND  = digital del STM32 y periferia lógica. Vertido bajo el MCU.
IOGND = isla del ESP32. AISLADA (sin net-tie a DGND).

Uniones (una sola por par):
   AGND ↔ DGND  en NT1, físicamente bajo el pin VREF− / punto de estrella del ADC.
   DGND ↔ PGND  en NT2, en el punto donde el sense de DC_N entra al acondicionamiento.
Ninguna señal cruza un "gap" entre vertidos. Sin plano partido bajo pistas.
```

---

## SHEET 08 — Protección HW + I/O  (`sch/protection_io.kicad_sch`)

| Ref | Valor | Footprint | Símbolo | Notas |
|---|---|---|---|---|
| U_CMP1..3 | comparador rápido ×4 (`TLV3604`, `LM339`) | `SOIC-14` | `Comparator:LM339` | OC/OV/OT con ventana + histéresis |
| U_OR1 | AND/OR lógico (`74LVC1G332`, `74LVC08`) | `SOT-23` | `74xGxxx` | agrega `OC*`,`OV`,`OT`,`FLT_1..6`,`UVLO`,`ESTOP` → `/FAULT` |
| U_LATCH | SR latch (`74LVC1G74` o discretos) | `SOT-23` | — | latch de `/FAULT`; RESET por SW2 |
| SW2 | pulsador RESET FALLA | `SW_Push` | `Switch` | |
| U_WDT | watchdog externo (`TPS3823`, `MAX6369`) | `SOT-23-5` | — | `WDI` del STM32; timeout → `/FAULT` + abre K1 |
| Q_K1..Q_FAN | MOSFET low-side (`AO3400`) + `D_fw` | `SOT-23` | `Q_NMOS` + `Device:D` | bobinas K1/K2/FAN/freno |
| J_ESTOP | bornera 2 vías contacto seco | `Screw_Terminal_01x02` | `Connector` | redundante, optoacoplado |
| U_ESTOPopto | `TLP293` ×2 | `SOIC-4` | `Isolator:` | e-stop → lógica + corte de K1 |
| D_LED_* | PWR/RUN/FAULT | `LED_0805` | `Device:LED` | + R |

```
Entradas a U_OR1:  OC_IAFE_A/B/C, OC_IMOT_U/V/W, OV_DC, OT, FLT_1..6, UVLO_BIAS, ESTOP_n
Salida:            /FAULT ─┬─ TIM1.BKIN / TIM1.BKIN2 / TIM8.BKIN   (PWM OFF por hardware)
                           ├─ U_LATCH.S    (queda enclavado)
                           └─ Q_K1 OFF     (abre contactor de línea)
RESET (SW2) sólo limpia el latch si /FAULT ya está inactivo (causa despejada).
WDI: pulso del STM32 cada < T_wdt; si falta → mismo camino que /FAULT.
```

---

## SHEET 09 — Aux + Bias  (`sch/psu_aux.kicad_sch`)

| Ref | Valor | Footprint | Símbolo | Notas |
|---|---|---|---|---|
| J_AUX | bornera 24 Vdc | `Screw_Terminal_01x02` | `Connector` | fuente DIN externa |
| D_rev, TVS, F_aux | prot. entrada | — | `Device:D`,`Device:D_TVS`,`Device:Fuse` | reverse + surge + fusible |
| U_BUCK15 | 24→15 V (`LMR33630`) | `HSOP-8` | `Regulator_Switching` | `+15V` |
| U_BUCK5 | 24→5 V | `SOT-23` / módulo | — | `+5V` |
| U_LDO33 | 5→3V3 | `SOT-23-5` | `Regulator_Linear` | `+3V3` limpio |
| U_INV15 | 15→−15 V (`LM27762`/charge pump) | `WSON` | — | `-15V` si el AFE analógico lo pide |
| U_BIAS1..6 | DC-DC aislado 15 V→ +15/−4 V 2 W | huella módulo o `SN6505+trafo` | `Converter_DCDC` | `+15Vg n`,`-4Vg n`,`GNDg n` |
| U_ISO_ESP | DC-DC aislado 5→3V3 1 W | huella módulo | — | isla `+3V3_IO` / `IOGND` |
| U_SUP | supervisor / secuenciador (`TPS3808`) | `SOT-23` | — | habilita `EN_PWR` sólo con `+15V` y bias OK |
| C_bulk | 2× 470 µF/35 V + cerámicos | `CP_Radial` | `Device:C_Polarized` | en 24 V y 15 V |

```
Secuencia POR:  +15V y +15Vg1..6 estables  →  U_SUP libera  →  EN_PWR alto permitido.
Si cae cualquier bias de gate → UVLO_BIAS → /FAULT (sheet 08).
```

---

## SHEET 10 — Aislamiento Comms  (`sch/isolation_comms.kicad_sch`)

| Ref | Valor | Footprint | Símbolo | Notas |
|---|---|---|---|---|
| U_ISO1 | `ISO7741` (4 ch, 2F/2R config.) | `SOIC-16W` | `Isolator:ISO7741` | UART TX/RX + 2 líneas heartbeat |
| C_iso | 100 nF + 10 µF ×2 lados | `C_0603`,`C_0805` | `Device:C` | en VCC1/VCC2 pegados |
| J_DBG | header 4 pin | `PinHeader_1x04` | `Connector` | acceso al enlace para debug |
| (ranura) | fresado Edge.Cuts bajo U_ISO1 | — | — | si creepage de paquete < 4 mm |

```
Lado CTRL:  VCC1 ← +3V3 ; GND1 ← DGND ; INA ← ISO_UART_TX ; OUTB → ISO_UART_RX ;
            heartbeat: OUT/IN ↔ ISO_HB_A/B
Lado IO:    VCC2 ← +3V3_IO ; GND2 ← IOGND ; señales espejo al ESP32 (sheet 11)
SIN net-tie GND1↔GND2.
```

---

## SHEET 11 — ESP32-S3 IoT  (`sch/esp32_iot.kicad_sch`)

| Ref | Valor | Footprint | Símbolo | Notas |
|---|---|---|---|---|
| U_ESP | ESP32-S3-WROOM-1-N8 | `RF_Module:ESP32-S3-WROOM-1` | mismo | keep-out de antena |
| C_esp | 10 µF + 100 nF ×varios | `C_0805/0603` | `Device:C` | en 3V3 del módulo |
| U_USB | USB-C + `CH340`/nativo | `USB_C_Receptacle...` | `Connector` | consola / flash / OTA |
| SW_EN, SW_BOOT | pulsadores | `SW_Push` | `Switch` | + RC en EN |
| U_PHY (opc.) | `LAN8720A` + RJ45 magjack | `QFN-24`, `RJ45` | `lan8720` | Modbus TCP por Ethernet |
| J_FIELD | bornera para señales de campo aisladas | `Screw_Terminal` | `Connector` | DI/DO opcionales de planta |
| D_LED_IO | link / MQTT / fault-mirror | `LED_0805` | `Device:LED` | |

```
Alimentación: +3V3_IO / IOGND (de sheet 09/10).  O USB-C.  O PoE externo.
Enlace: UART aislado desde sheet 10.  RMII al PHY si se usa Ethernet.
Todo IOGND. Nada cruza a DGND salvo por U_ISO1.
```

---

## Checklist de salida de la captura (antes de pasar a PCB)

- [ ] ERC sin errores (warnings revisados uno a uno).
- [ ] Todas las etiquetas jerárquicas tienen par (sin nets colgando entre hojas).
- [ ] Cada net asignada a su net class correcta (revisar en Schematic Setup).
- [ ] `NT1` (AGND↔DGND) y `NT2` (DGND↔PGND) presentes y únicos. `IOGND` sin net-tie.
- [ ] BOM exportada; footprints asignados al 100 % (CvPcb) y verificados en 3D.
- [ ] Símbolos de fabricante (drivers, aisladores, ESP32, STM32) validados pin a pin
      contra el datasheet.
- [ ] Anotación final hecha (`Tools → Annotate`, sequential por hoja).

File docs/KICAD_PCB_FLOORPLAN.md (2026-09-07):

# PCB — Stackup, Floorplan, Zonas y Orden de Ruteo

> Se ejecuta **dentro de Pcbnew** tras cerrar la captura y el ERC. Este documento
> es el guion. El ruteo fino lo hacemos por bloques y lo reviso yo antes de
> fabricar. No mandes a fábrica sin DRC limpio + revisión 3D + verificación de
> creepage con footprints reales.

---

## 1. Stackup (Board Setup → Physical Stackup)

**4 capas, 1.6 mm, cobre 70 µm (2 oz) en externas, 35 µm en internas.**

| Capa | Uso | Cobre |
|---|---|---|
| **F.Cu** | Potencia lado A: `DC_P` en zona de puentes (laminado con B.Cu), nodos `SW_*`, lazos de gate, componentes de potencia | 70 µm |
| **In1.Cu** | `PGND` sólido bajo toda la zona de potencia. En la zona de control, mismo plano físico usado como `AGND` (separados por hueco, unidos sólo en `NT1`). | 35 µm |
| **In2.Cu** | Planos de alimentación troceados: `+15V`, `+5V`, `+3V3`, `+3V3_ANA`, islas de `+15Vg1..6`. Bajo el MCU: `DGND`. | 35 µm |
| **B.Cu** | Potencia lado B: `DC_N` en zona de puentes (laminado con F.Cu), retorno de conmutación. En zona control: señales + `DGND`/`IOGND`. | 70 µm |

- Dieléctrico F↔In1: **fino (≈ 0.2 mm)** en la zona de potencia para bajar la
  inductancia del bus laminado `DC_P`(F) / `DC_N`(B) — si el fabricante lo permite
  por sub-zona, si no, todo a 0.2–0.3 mm y compénsalo con núcleo grueso In1↔In2.
- Control de impedancia: sólo importa en RMII del PHY (50 Ω single-end) y USB
  (90 Ω dif). Define esas dos net classes de impedancia si usas Ethernet/USB.
- Para > 20 kW o EMC exigente: subir a **6 capas** (Sig / GND / Pwr / GND / Sig / Sig).

---

## 2. Floorplan (partición física — flujo de energía en una sola dirección)

```
  ┌──────────────────────────────────────────────────────────────────────────────┐
  │  ZONA HV (roja)                                    │  ZONA LV (azul/verde)     │
  │                                                    │                           │
  │  [J1 red] → [F1-3] → [K1] → [EMC/CM] → [LCL:       │                           │
  │   L2,Cf,Rd,L1]  ─────────────►  [AFE: Q1..Q6       │   ┌── BARRERA ─────────┐  │
  │                                  + Cdec + snubber] │   │ opto/aisladores    │  │
  │                                        │           │   │ + trafos de gate   │  │
  │                                   [SW_A/B/C]       │   │ (05, 10)           │  │
  │                                        │           │   └────────────────────┘  │
  │   [Precarga Rpc+K2] ── [BANCO C_dc] ═══╪═══════╗   │  [06 AFE analógico]       │
  │   [Chopper Qbrk+Jbrk] ──────────────── DC_P/DC_N   │  [Vref] [07 STM32]        │
  │                                        │           │  [08 Protección HW]       │
  │                                  [INV: Q7..Q12     │  [09 Aux + bias]          │
  │                                   + Cdec] ────────►│  ── BARRERA FUNCIONAL ──  │
  │                                   [SW_U/V/W]       │  [10 ISO] [11 ESP32]      │
  │                                        │           │  [antena keep-out]        │
  │                                  [L_CM2] → [J_MOT] │  [J_DBG][USB-C][RJ45]     │
  └──────────────────────────────────────────────────────────────────────────────┘
     Disipador común a lo largo del borde inferior de la ZONA HV (AFE + INV + chopper)
     con NTC en 2 puntos.  Ventilador soplando a lo largo del disipador.
```

Principios:
1. **Energía fluye de izquierda a derecha** (red→LCL→AFE→bus→INV→motor). Nada
   regresa cruzando bloques ya "usados".
2. **Una sola barrera de seguridad** recta que cruza la placa entre ZONA HV y
   ZONA LV. Los drivers (05) y los aisladores de comms (10) son los únicos
   componentes que la pisan. Dibuja `Rule Area "ISO_BARRIER"` en In1/In2/B.Cu a
   lo largo de ella → la regla 9 del DRC prohíbe cobre dentro.
3. **Segunda barrera, funcional**, entre dominio CTRL y dominio IoT (ESP32). 4 mm.
4. Banco `C_dc` **entre** AFE e INV, lo más cerca posible de ambos puentes; el bus
   `DC_P/DC_N` como par laminado F/B, sin interrupciones.
5. Sección analógica (06 + Vref + entradas de ADC del 07) **agrupada y lejos** de
   `SW_*`, de los magnéticos y del ESP32/RF.
6. Conectores de campo (red, motor, freno, 24 V) en **bordes opuestos**: red y
   motor no comparten borde.

---

## 3. Zonas de cobre (Add Zone)

| Zona | Capa | Net | Prioridad | Límite |
|---|---|---|---|---|
| Bus + | F.Cu | `DC_P` | 60 | sólo dentro de ZONA HV, sobre banco y puentes |
| Bus − | B.Cu | `DC_N` | 60 | espejo exacto de `DC_P` (laminado) |
| PGND potencia | In1.Cu | `PGND` | 50 | toda la ZONA HV; hueco de aislamiento hacia AGND |
| AGND analógico | In1.Cu | `AGND` | 50 | sólo bajo sección 06 + Vref + pines ADC; se une a PGND vía `NT1` únicamente |
| DGND | In2.Cu / B.Cu | `DGND` | 45 | bajo STM32 y lógica |
| IOGND | In2.Cu / B.Cu | `IOGND` | 45 | sólo bajo dominio ESP32; **sin** unión a DGND |
| +15V / +5V / +3V3 / +3V3_ANA | In2.Cu | resp. | 40 | islas, no solapan |
| +15Vg1..6 | In2.Cu | resp. | 40 | isla flotante por rama, sobre cada driver |
| PE / CHASSIS | F.Cu + B.Cu | `PE` | 30 | anillo de guarda en el borde, stitching, a espárragos de montaje |

- **Ninguna** pista de señal cruza el hueco entre `PGND` y `AGND`, ni entre islas
  de alimentación. Si una señal debe cruzar, su retorno cruza con ella (misma
  ranura, mismo punto).
- Stitching de vías `PGND`↔`In1` cada ~5 mm en la zona de potencia.
- Y-caps (`CY`) de `PGND` y `DGND` a `PE` junto a la barrera, para el retorno de
  corriente de modo común.

---

## 4. Reglas de ruteo por bloque (alta dv/dt · di/dt)

### 4.1 Lazo de conmutación (AFE e INV) — lo primero que se rutea

- Orden de colocación por rama: `DC_P (F) → Qx_alto → Qx_bajo → DC_N (B)` con
  `Cdec (1 µF/1 kV)` justo cruzando `DC_P/DC_N` **a < 10 mm** del par de MOSFET.
- Objetivo `L_lazo < 20 nH`. Sobretensión estimada:
  `V_pico = V_dc + L_lazo · di/dt`; con `di/dt ≈ 20 A / 20 ns = 1e9 A/s` y 20 nH →
  **+20 V** sobre 800 V → OK bajo 1200 V. Mide en bench con sonda diferencial HV.
- `DC_P` y `DC_N` **solapados en F/B** en toda la trayectoria (cancelación de campo).
- Varias vías en paralelo (≥ 4, ⌀ 0.6/1.2) en cada transición de `DC_P`/`DC_N`.

### 4.2 Nodo de conmutación `SW_*`

- Cobre **sólo lo necesario** por ampacidad/térmico; es el agresor de dv/dt.
- Lejos de: sección analógica, lazos de gate de *otras* ramas, barrera de aislam.
- **No** inundar `PGND` hasta el borde de `SW_*`: dejar hueco + anillo de guarda
  `PGND` a distancia (reduce inyección capacitiva).

### 4.3 Lazo de gate

- `G_Hx` + `Rg` + `KELVIN_Hx` como **par apretado** (adyacentes en capa, o F sobre
  In1-guard), área de lazo **< 1 cm²**.
- `Rg` y clamp de Miller **en el pie del MOSFET**, no en el driver.
- Bias del driver (`+15Vg/-4Vg`) con `1 µF + 100 nF` en el pin y otro par en el SiC.
- Driver a **< 15 mm** del MOSFET.

### 4.4 Bus laminado y banco

- `C_dc` repartido: los de HF (`2.2 µF film`) pegados a cada puente; el grueso en
  el centro. Todas las conexiones al bus por el par laminado, sin "stubs".

### 4.5 Analógico

- Pistas de sensor como **diferenciales guardadas**, sobre `AGND` continuo.
- Cruzar pistas de potencia **a 90°** y en capa distinta.
- `Vref` en **estrella** al pin del ADC; `10 µF+100 nF` dedicados.
- Filtro anti-alias y `33 Ω + 1 nF` **en el pin del ADC**.

### 4.6 EMI de entrada/salida

- CM choke de entrada + X/Y caps junto a `J1`. CM choke de salida junto a `J_MOT`.
- Shield del cable de motor con **abrazadera 360°** a `PE` en el conector.
- Anillo de guarda `PE` en todo el borde, stitching cada ~10 mm, a los 4+
  espárragos de montaje (contacto metálico con el gabinete).

---

## 5. Orden de ruteo (secuencia recomendada en Pcbnew)

1. Colocar contornos: `Edge.Cuts` de la placa + `Rule Area "ISO_BARRIER"` + keep-out
   de antena ESP32 + agujeros de montaje (M3/M4, uno por esquina + centro de la
   zona de potencia bajo el disipador).
2. Colocar los **12 MOSFET + Cdec + banco C_dc + bus** y rutear **4.1** (lazos de
   conmutación) y **4.4** (bus laminado). Correr DRC.
3. Colocar los **6 drivers** sobre la barrera y rutear **4.3** (gate) + bias.
4. Colocar **LCL, EMC, precarga, chopper, borneras HV** y rutear la potencia AC.
5. Colocar **sección analógica (06) + Vref** y rutear **4.5**. Verter `AGND`.
6. Colocar **STM32 (07)** y rutear PWM→drivers, ADC←analógico, BKIN←`/FAULT`.
   Colocar `NT1`, `NT2`.
7. Colocar **protección (08)** y rutear cadena de fallo + mando de relés.
8. Colocar **aux/bias (09)** y planos de alimentación (In2).
9. Colocar **ISO comms (10) + ESP32 (11)** y rutear enlace aislado + Ethernet/USB.
   Verter `IOGND`, barrera funcional 4 mm.
10. Vertidos finales (`DC_P`,`DC_N`,`PGND`,`DGND`,`PE`), stitching, teardrops.
11. **DRC completo** (con reglas custom) → 0 errores. Revisar cada warning.
12. Vista 3D: comprobar choque de cuerpos, courtyards, altura bajo disipador,
    y **medir a ojo el creepage real** entre cobre HV y cobre LV con footprints
    reales (KiCad 8 lo reporta, pero confírmalo en los puntos críticos).
13. Fabricación: Gerbers X2, mapa de taladros, `.drl`, IPC-2581/ODB++ si tu
    fábrica lo acepta; nota de stackup y cobre 2 oz explícita.

---

## 6. Checklist de salida de PCB (antes de fabricar)

- [ ] DRC con `kicad/drc_custom_rules.txt` cargadas: **0 errores**.
- [ ] `ISO_BARRIER` sin cobre; creepage HV↔LV ≥ 8 mm medido en 3+ puntos peores.
- [ ] `DC_P`/`DC_N` laminados y sin interrupción; `L_lazo` estimada < 20 nH.
- [ ] `NT1` (AGND↔DGND) y `NT2` (DGND↔PGND) únicos; `IOGND` aislado.
- [ ] Todos los `SW_*` alejados de analógico y barrera; guarda `PGND` con hueco.
- [ ] Lazos de gate < 1 cm²; `Rg`/clamp en el pie del MOSFET.
- [ ] Disipador: Rth_s-a objetivo ≤ 0.3 °C/W con ventilador; NTC en 2 puntos.
- [ ] Anillo `PE` + stitching + abrazadera de shield de motor.
- [ ] Fiduciales (3), test points de bring-up accesibles (ver `06_bringup...md`).
- [ ] Silk: rótulo "⚠ HV — 800 V — DESCARGAR ANTES DE MANIPULAR" y LED BUS-LIVE.

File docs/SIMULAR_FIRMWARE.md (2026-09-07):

# Simular el firmware: qué se puede y qué no

> Respuesta directa a "¿se puede cargar el firmware en Proteus / KiCad y
> simularlo?". La conclusión honesta primero, y luego lo que sí funciona.

---

## 1. Proteus — sí co-simula firmware, pero no éste

Proteus VSM **sí** ejecuta un `.hex`/`.elf` dentro de un modelo de MCU y lo
co-simula con el circuito. Eso es real y es su mayor virtud. **Pero para este
proyecto no sirve**, por tres razones concretas:

**a) No existe el modelo del STM32G474.** Comprobado en tu instalación
(`Proteus 8 Professional`), sus librerías de núcleo ARM contienen exactamente:

| Librería | Dispositivos soportados |
|---|---|
| `CM3_STM32.LIB` | STM32F103 C4/C6/C8, R4/R6, T4/T6 |
| `CM4_STM32.LIB` | STM32F401 CB/CC/CD/CE, RB/RC/RD/RE, VB/VC/VD/VE |

No hay familia G. Ni una referencia.

**b) Aunque lo hubiera, este diseño vive de periféricos que VSM no modela con
fidelidad**: salidas complementarias del timer avanzado con **inserción de
dead-time por hardware**, entradas `BKIN` de parada, y **conversiones
inyectadas del ADC disparadas por el timer en el centro del PWM**. Proteus
modela bien el núcleo; los rincones del periférico avanzado son justo donde
sus modelos flaquean — y esos rincones *son* el diseño.

**c) Escala de tiempo.** Co-simular el lazo de 16 kHz durante los 0.6 s del
ensayo de frenado son ~10 000 periodos de PWM con paso analógico
sub-microsegundo. Eso en Proteus son horas o días, y la parte analógica de un
convertidor de 15 kVA no es su fuerte.

## 2. KiCad — no ejecuta firmware, punto

El simulador de KiCad es **ngspice**: un simulador de circuito puro. No tiene
modelo de núcleo ARM ni forma de ejecutar código. Eso no va a cambiar.

## 3. Lo que sí se hace (y es lo que hace la industria)

En control de motores nadie valida el firmware metiendo el MCU en un
simulador de circuito. Se hace en tres capas, y las tres están montadas aquí:

### Capa 1 — SIL: el algoritmo real contra la planta validada

`fw/verify/control_ref.py` es la **transliteración literal** de
`fw/Core/Inc/b2b_control.h`: mismo PI con anti-windup, misma Clarke/Park,
mismo SVPWM por inyección de secuencia cero, mismo PLL normalizado.

Y no duplica constantes: **lee los `#define` directamente de
`b2b_config.h`**, que a su vez lo genera `fw/config/gen_config.py` desde
`sim/b2b_params.py`. Cadena completa:

```
sim/b2b_params.py  ──►  gen_config.py  ──►  b2b_config.h  ──►  firmware C
       │                                          │
       └──► simulación validada                   └──► control_ref.py (SIL)
```

Si cambias un parámetro, todo se regenera y nada se desincroniza.

### Capa 2 — el PWM real del firmware dentro del circuito de KiCad

`kicad/sim/fw_bridge.kicad_sch` es un puente trifásico SiC completo cuyas seis
fuentes de puerta **no son formas de onda inventadas**: son los flancos que
produce el código de control real, incluyendo el dead-time de 500 ns que
inserta el `TIM1`. Los genera `tools/gen_kicad_sim.py` llamando a
`control_ref.py` y volcando el resultado como fuentes `VPWL`.

O sea: el firmware no *se ejecuta* dentro de KiCad, pero **su salida real sí
gobierna el circuito**. Para validar la capa de modulación (que es lo que
querrías comprobar en Proteus) esto da más información y corre en segundos.

### Capa 3 — HIL, cuando exista la placa

Con el hardware fabricado: PWM a un puente de baja tensión, cargas RL, sondas
diferenciales. Es el paso 5 del `docs/06_bringup...` (pendiente de escribir).

## 4. Los tres esquemas simulables en KiCad

En `kicad/sim/`. Se abren y se simulan con **Inspeccionar → Simulador**.

| Archivo | Análisis | Qué comprueba |
|---|---|---|
| `lcl_ac.kicad_sch` | `.ac dec 400 10 200k` | Resonancia del LCL en 2431 Hz y pico amortiguado de 19 dB |
| `halfbridge.kicad_sch` | `.tran 0.02n 5.2u` | Sobretensión de conmutación según la inductancia del lazo |
| `fw_bridge.kicad_sch` | `.tran 20n 375u` | Puente gobernado por el PWM real del firmware |

`sic.lib` lleva el modelo VDMOS del SiC (aproximado: sirve para evaluar
parásitas de layout, no para pérdidas exactas).

### Verificación cruzada

`tools/verify_kicad_sim.py` cierra el círculo:

```
esquema de KiCad  →  kicad-cli exporta netlist SPICE  →  se ejecuta
                  →  se compara con el modelo analítico validado
```

Tres modelos independientes (analítico, LTspice y el circuito dibujado en
KiCad) tienen que dar lo mismo. Si divergen, hay un error en alguno.

## 5. Si aun así quieres ver co-simulación en Proteus

Es legítimo como demostrador didáctico. El camino honesto sería un
**STM32F401** (sí soportado) corriendo una versión *reducida* del control:
generación de SVPWM con dead-time sobre un puente trifásico de baja tensión.

Dos avisos: **(a)** valida la lógica de modulación, no el firmware del G474 —
los periféricos son distintos; **(b)** el formato de proyecto de Proteus
(`.pdsprj`) es binario propietario y no lo puedo generar: tendrías que montar
el esquema a mano, yo te daría el firmware del F401 y la lista de conexiones.

Dímelo si lo quieres y lo preparo.

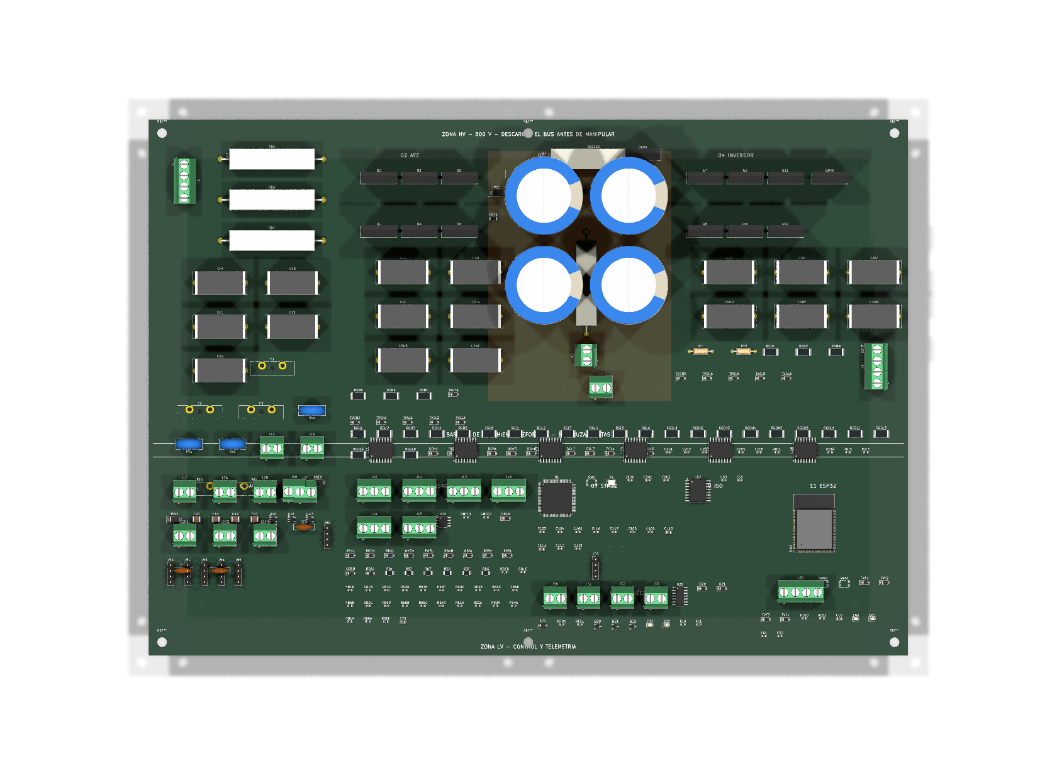
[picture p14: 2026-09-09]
render/b2b_top.png

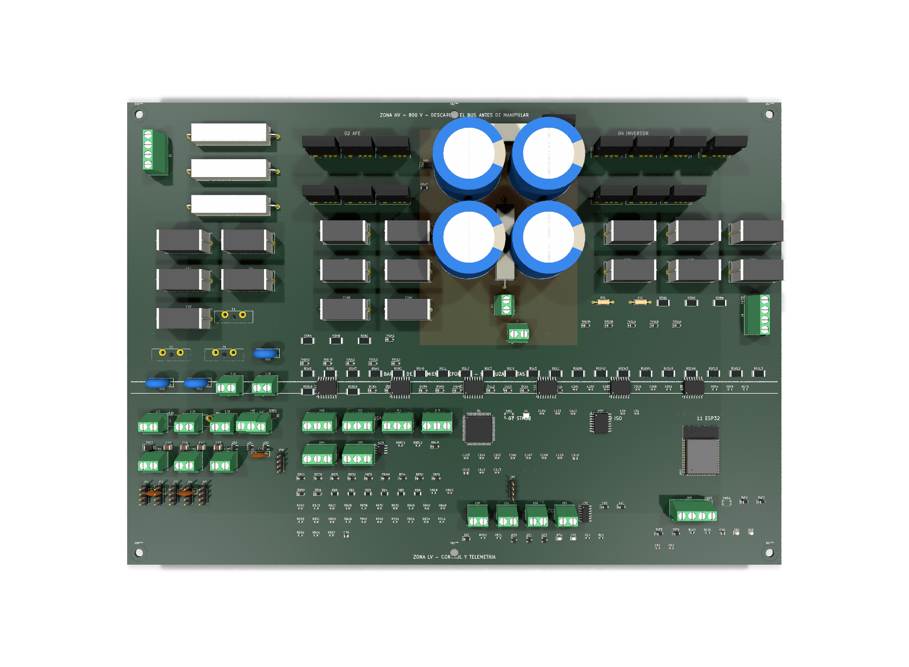
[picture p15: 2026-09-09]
render/b2b_iso.png

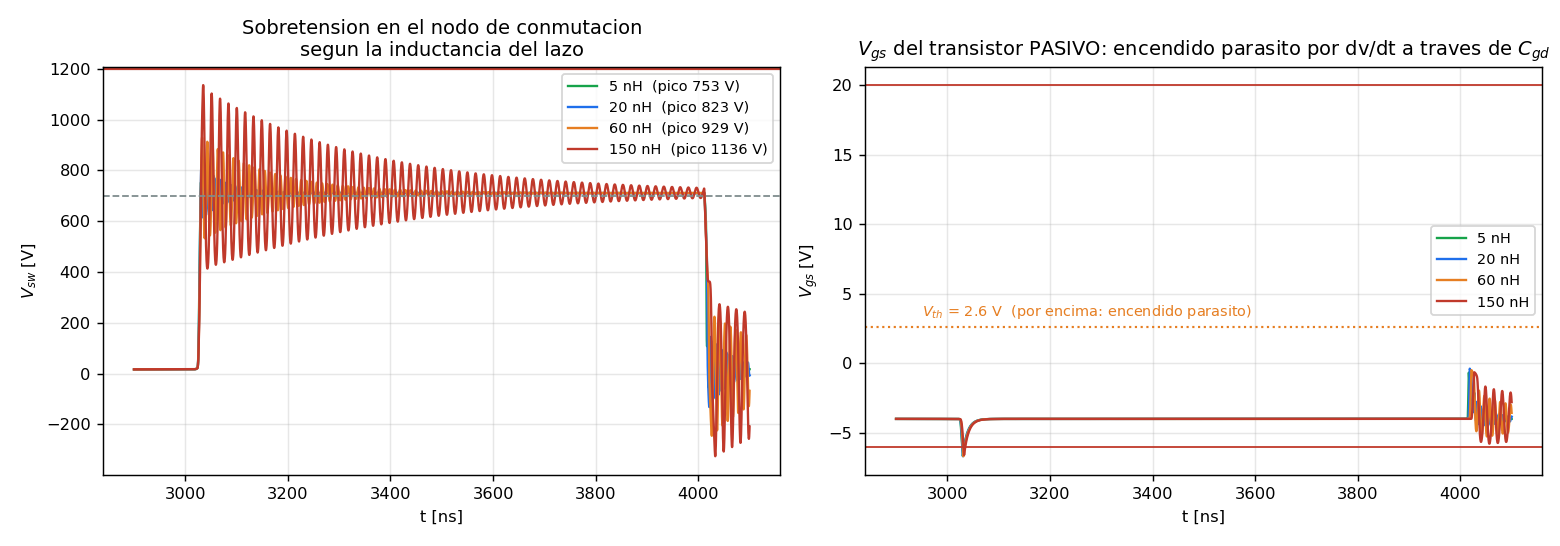
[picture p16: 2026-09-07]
sim/out/06_spice_halfbridge.png

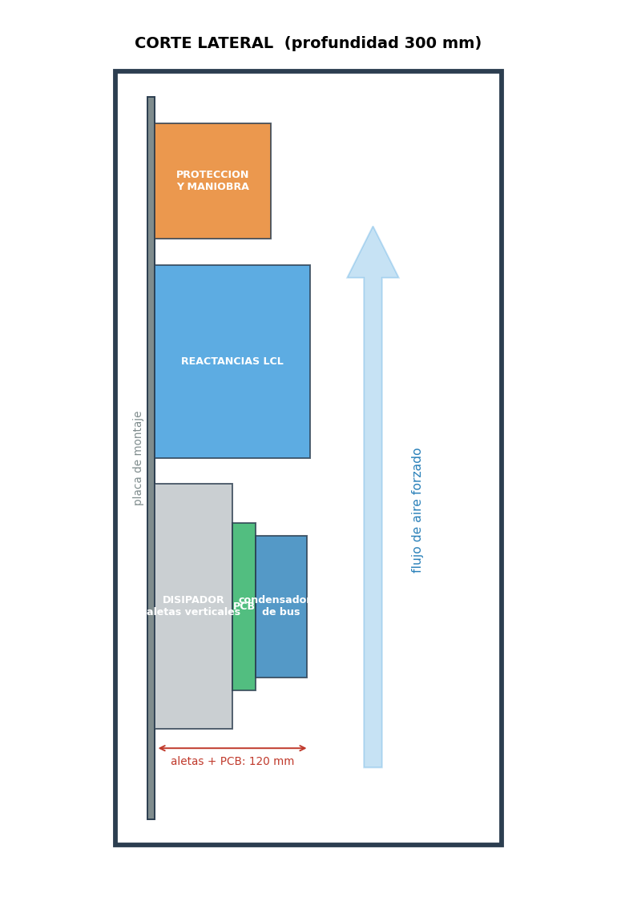
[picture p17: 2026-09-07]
mech/out/gabinete_lateral.png

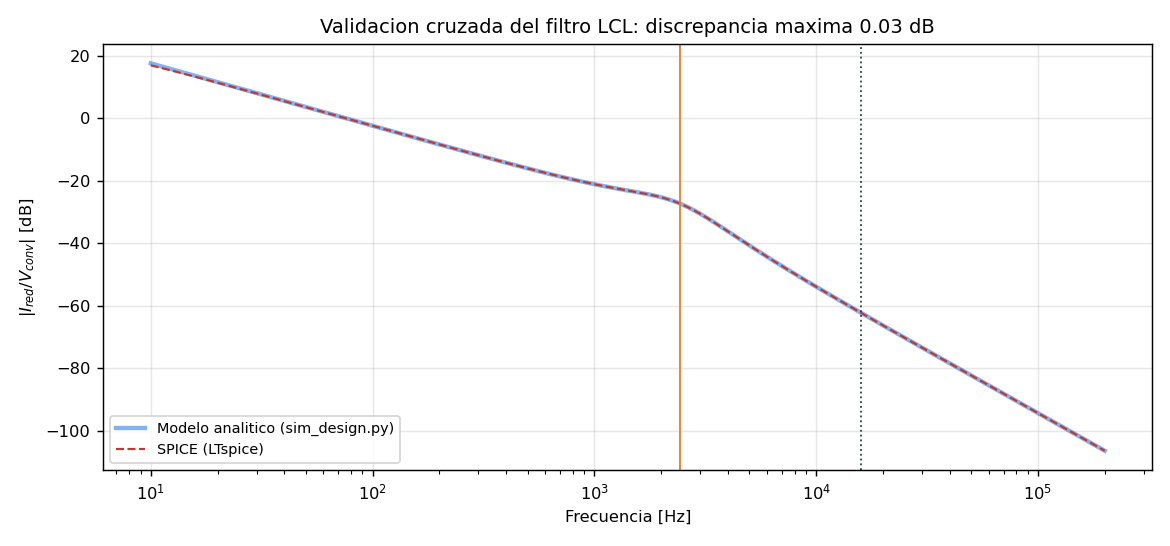
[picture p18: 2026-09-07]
sim/out/07_spice_lcl.png

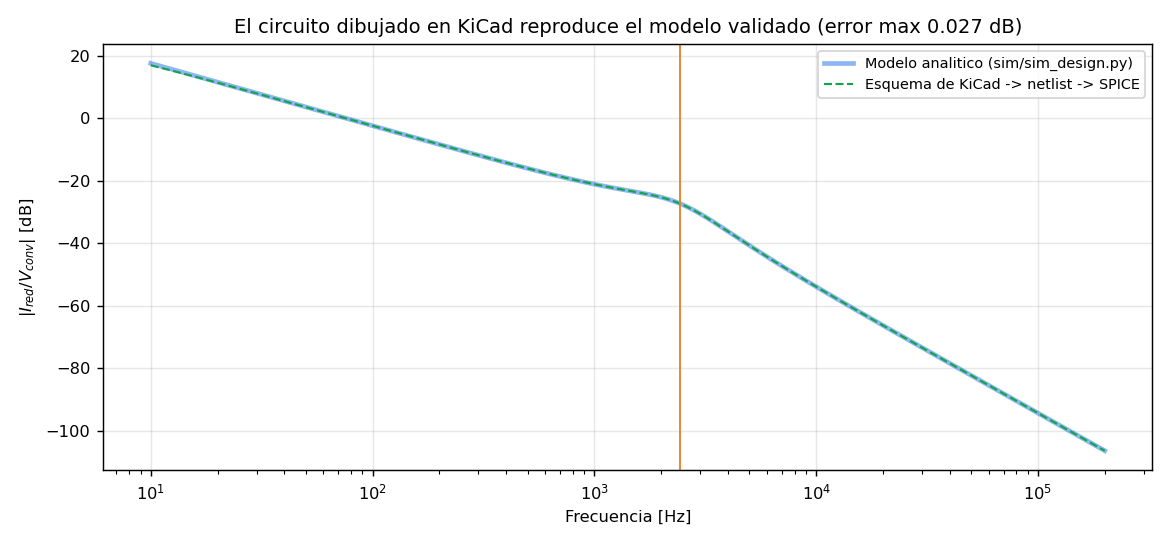
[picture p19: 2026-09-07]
sim/out/09_kicad_lcl.png

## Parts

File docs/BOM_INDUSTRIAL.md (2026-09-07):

# BOM industrial — marcas y referencias reales

> Punto de diseño: **15 kVA · 400 V_LL · 60 Hz · V_dc ≤ 800 V · f_sw 16 kHz**.
> Todas las referencias son de catálogo vigente y de distribución habitual
> (Digi-Key / Mouser / Farnell / RS). Donde hay dos marcas, la primera es la
> recomendada y la segunda el segundo origen (*second source*).

---

## 1. Semiconductores de potencia

| Ref | Cant | Descripción | Marca | Referencia (MPN) | Notas |
|---|:-:|---|---|---|---|
| Q1–Q12 | 12 | SiC MOSFET 1200 V, 40 mΩ, TO-247-**4** (pin Kelvin) | **Wolfspeed** | `C3M0040120K` | **el que hay que montar**. 17.5 W/dispositivo |
| — | — | *2.º origen, pin-compatible* | Infineon | `IMZA120R030M1H` | CoolSiC 1200 V 30 mΩ |
| — | — | *el de la librería KiCad, 75 mΩ* | Wolfspeed | `C3M0075120K` | válido solo hasta ~10 kVA |
| QBRK | 1 | SiC chopper de frenado | Wolfspeed | `C3M0040120K` | mismo encapsulado |
| DBRK | 1 | Diodo SiC Schottky 1200 V / 30 A | Wolfspeed | `C4D20120A` | freewheel del chopper |
| — | 12 | Aislador térmico + tornillería TO-247 | Bergquist / Laird | `SIL-PAD 2000` + M3 | 0.3 °C/W |

## 2. Gate drivers y su alimentación

| Ref | Cant | Descripción | Marca | Referencia (MPN) | Notas |
|---|:-:|---|---|---|---|
| U11–U16 | 6 | Driver aislado doble, DESAT + Miller clamp, CMTI 150 V/ns | **Texas Instruments** | `UCC21750QDWRQ1` | **recomendado**: el CMTI de 150 V/ns cubre los 147 V/ns medidos |
| — | 6 | *alternativa del esquemático actual*, CMTI 100 V/ns | Texas Instruments | `UCC21520DW` | **exige el snubber de 220 pF** (ver §9) |
| — | 6 | *2.º origen* | STMicroelectronics | `STGAP2SMTR` | ecosistema ST, encaja con el STM32 |
| U_BIAS1–6 | 6 | DC-DC aislado 2 W, +15 V / −4 V, 5.2 kV | **Murata** | `MGJ2D152005SC` | bias por rama, referido al Kelvin |
| — | 6 | *2.º origen* | RECOM | `RxxP21505D` | |
| Rg_on | 12 | 10 Ω 1 W 2512, baja inductancia | Vishay | `CRCW251210R0FKEG` | |
| Rg_off | 12 | 3.3 Ω 1 W 2512 | Vishay | `CRCW25123R30FKEG` | |
| D_off | 12 | Diodo rápido 200 V SOD-123 | Nexperia | `BAV21WS` | |
| TVS_gs | 12 | Zener doble +20 / −6 V | Nexperia | `PESD2CAN` / `BZX84C18` | protección de gate |

## 3. Bus DC y precarga

| Ref | Cant | Descripción | Marca | Referencia (MPN) | Notas |
|---|:-:|---|---|---|---|
| C1–C4 | 4 | Condensador DC-link film 150 µF / 900 V DC | **TDK / EPCOS** | `B32778G8157K000` | 600 µF totales, sin equilibrado |
| — | 4 | *2.º origen* | KEMET | `C4AQLBW5150A3NJ` | |
| — | 4 | *2.º origen* | Vishay | `MKP1848S61590JY5` | |
| C5, C6 | 2 | Film HF 2.2 µF / 1 kV, desacoplo de lazo | KEMET | `C4AQOBW5220A3NJ` | pegado a cada rama |
| Cdec | 6 | Film 1 µF / 1 kV, lazo de conmutación | TDK | `B32656S1105K` | **< 10 mm del par de MOSFET** |
| RPC | 1 | Resistencia de precarga 68 Ω, 200 W, pulso ≥ 350 J | **Arcol** | `HS100 68R J` | bobinada, con brida |
| — | 1 | *2.º origen* | Ohmite | `TGHG 68R` | |
| K2 | 1 | Contactor de bypass de precarga, 25 A, bobina 24 VDC | Schneider | `LC1D25BD` | |
| RBLEED | 1 | Bleeder 100 kΩ 3 W | Vishay | `PR03000201003JAC00` | descarga < 60 V en < 60 s |
| RBRK | 1 | Resistencia de frenado 12 Ω, 1.5 kW (externa) | **Danotherm** | `CBH 165 C 12R` | **fuera del gabinete** |

## 4. Filtro LCL y EMC de entrada

| Ref | Cant | Descripción | Marca | Referencia (MPN) | Notas |
|---|:-:|---|---|---|---|
| L1A–C | 3 | Reactancia 1.5 mH / 30 A, lado convertidor | **Block** | `DPU 1.5-30` | núcleo de hierro, montaje en placa |
| — | 3 | *2.º origen* | Schaffner | `RWK 305-30` | |
| L2A–C | 3 | Reactancia 0.6 mH / 30 A, lado red | Block | `DPU 0.6-30` | |
| CFA–C | 3 | Condensador de filtro 10 µF / 500 VAC | **TDK / EPCOS** | `B32924C3106M000` | clase X2, conexión Y |
| RDA–C | 3 | Amortiguamiento **6.8 Ω / 10 W** | Arcol | `HS10 6R8 J` | **valor optimizado por simulación** |
| L_CM1 | 1 | Choke de modo común trifásico 3 mH / 30 A | **Schaffner** | `RN142-30-33` | |
| FIL1 | 1 | Filtro EMC trifásico 30 A, EN 55011 clase A | **Schaffner** | `FN3258-30-33` | entrada de red |
| L_CM2 | 1 | Choke de modo común de salida a motor | Schaffner | `RWK 305-30-KL` | reduce corriente de fuga |
| RV1–3 | 3 | Varistor 300 VAC / 20 mm, clase II | TDK / EPCOS | `B72220S0301K101` | |

## 5. Protección y maniobra

| Ref | Cant | Descripción | Marca | Referencia (MPN) | Notas |
|---|:-:|---|---|---|---|
| F1–F3 | 3 | Fusible ultrarrápido 25 A, 690 V, aR | **Mersen** | `FR14GG69V25` | protección de semiconductores |
| — | 3 | *2.º origen* | Eaton / Bussmann | `FWP-25A14F` | |
| — | 1 | Portafusibles 3P para 14×51 | Mersen | `US14 3P` | carril DIN |
| K1 | 1 | Contactor de línea 3P 25 A, bobina 24 VDC | **Schneider** | `LC1D25BD` | |
| — | 1 | *2.º origen* | Siemens | `3RT2026-1BB40` | |
| QS1 | 1 | Seccionador de carga 32 A con mando en puerta | Schneider | `VBF2` + `KCF1PZ` | enclavamiento de puerta |
| S_ESTOP | 1 | Seta de emergencia, 2 NC, IP66 | **Schneider** | `XALK178G` | contacto seco redundante |
| F10 | 1 | Fusible auxiliar 3 A, 5×20 | Schurter | `0034.3122` | |

## 6. Sensado

| Ref | Cant | Descripción | Marca | Referencia (MPN) | Notas |
|---|:-:|---|---|---|---|
| J10–J15 | 6 | Transductor Hall de lazo cerrado, ±50 A | **LEM** | `LKSR 50-NP` | 3 red + 3 motor |
| — | 6 | *2.º origen* | LEM | `HO 50-P/SP33` | salida en tensión |
| — | 6 | *alternativa: shunt + aislador* | Texas Instruments | `AMC1305M25` + shunt 1 mΩ Vishay `WSLP` | mejor exactitud, más firmware |
| U_V | 7 | Amplificador aislado, entrada alta Z | Texas Instruments | `AMC1311DWV` | Vdc + Vred + Vmotor |
| U20 | 1 | Amp. operacional dual, zero-drift | Texas Instruments | `OPA2320AIDR` | acondicionamiento |
| U_REF | 1 | Referencia 3.000 V, 3 ppm/°C | **Texas Instruments** | `REF5030AIDR` | referencia del ADC |
| RT1, RT2 | 2 | NTC 10 kΩ B3950 con terminal a tornillo | **Vishay** | `NTCALUG03A103G` | disipador y módulo |
| Rburden | 6 | 100 Ω 0.1 % 25 ppm 1206 | Susumu | `RG3216P-101-B-T5` | precisión del sensado |
| Rdiv | 35 | 200 kΩ 0.1 % 25 ppm 1206, 200 V | Vishay | `MMB02070C2003FB200` | divisores de alta tensión |

## 7. Control y comunicaciones

| Ref | Cant | Descripción | Marca | Referencia (MPN) | Notas |
|---|:-:|---|---|---|---|
| U1 | 1 | MCU Cortex-M4F 170 MHz, HRTIM, 5×ADC, CORDIC | **STMicroelectronics** | `STM32G474VET6` | LQFP-100 |
| U50 | 1 | Aislador digital cuádruple 3F/1R, reforzado | **Analog Devices** | `ADuM1401ARWZ` | barrera STM32↔ESP32 |
| — | 1 | *2.º origen* | Texas Instruments | `ISO7741DWR` | |
| U60 | 1 | Módulo Wi-Fi/BT, 8 MB flash | **Espressif** | `ESP32-S3-WROOM-1-N8` | telemetría |
| U30 | 1 | Comparador cuádruple | Texas Instruments | `LM339DR` | cadena de falla |
| — | 1 | *recomendado: comparador rápido* | Texas Instruments | `TLV3604DCKR` | 1.4 ns, mejor para OC |
| U_WDT | 1 | Supervisor con watchdog | Texas Instruments | `TPS3823-33DBVR` | |
| X1 | 1 | Cristal 24 MHz ±10 ppm 3225 | Abracon | `ABM8G-24.000MHZ-4Y-T3` | |
| U40–42 | 3 | Reguladores 24→15→5→3.3 V | Texas Instruments | `LMR33630ADDA`, `TLV75833PDBVR` | |
| PSU1 | 1 | Fuente 24 V / 60 W, carril DIN | **Mean Well** | `DR-60-24` | auxiliar |
| — | 1 | *2.º origen industrial* | Phoenix Contact | `QUINT4-PS/1AC/24DC/2.5` | |

## 8. Borneras, conectores y cableado industrial

| Ref | Cant | Descripción | Marca | Referencia (MPN) | Notas |
|---|:-:|---|---|---|---|
| — | 4 | Bornera de potencia carril DIN 16 mm², 76 A | **Phoenix Contact** | `UK 16 N` (3004362) | L1/L2/L3/PE de red |
| — | 4 | idem para salida a motor | Phoenix Contact | `UK 16 N` | U/V/W/PE |
| — | 2 | Bornera de freno 10 mm² | Phoenix Contact | `UK 10 N` (3005073) | |
| — | 1 | Bornera de tierra a carril | Phoenix Contact | `USLKG 16` (3005044) | PE principal |
| — | 20 | Bornera de control 2.5 mm², resorte | **Weidmüller** | `A2C 2.5` (1991760000) | señales |
| — | 20 | *2.º origen* | Wago | `2002-1201` TOPJOB S | |
| — | 6 | Tapa final + tope de bornera | Phoenix Contact | `D-UK 16`, `CLIPFIX 35` | |
| J_MOT / J1 | 2 | Bornera de PCB 4 vías, 16 A, 5 mm | Phoenix Contact | `MKDSN 1,5/4-5,08` | en placa |
| — | 2 | Prensaestopas M32 metálico, apantallado EMC | **Lapp** | `SKINTOP MS-SC-M32` | red y motor, malla 360° |
| — | 1 | Prensaestopas M25 apantallado | Lapp | `SKINTOP MS-SC-M25` | freno |
| — | 2 | Prensaestopas M20 | Lapp | `SKINTOP ST-M20` | señal |
| — | 1 | Carril DIN 35 mm perforado, 1 m | Phoenix Contact | `NS 35/7,5 PERF` | |
| — | 20 m | Canaleta ranurada 40×60 | Phoenix Contact | `CD 40×60` | |
| — | — | Cable de motor apantallado 4G6 | **Lapp** | `ÖLFLEX SERVO 2YSLCY-JB` | malla al prensaestopas |
| — | — | Cable de señal apantallado 2×0.75 | Lapp | `UNITRONIC LiYCY` | sensores |

## 9. Mecánica, refrigeración y gabinete

| Ref | Cant | Descripción | Marca | Referencia (MPN) | Notas |
|---|:-:|---|---|---|---|
| GAB | 1 | Armario mural chapa 800×600×300, IP66 | **Rittal** | `AE 1180.500` | con placa de montaje |
| — | 1 | *2.º origen* | Hammond | `1418N4L16couplé` / Fibox `ARCA` | |
| VENT | 1 | Ventilador con filtro 180 m³/h, 24 V | **Rittal** | `SK 3241.100` | **obligatorio** (ver §10) |
| SAL | 1 | Rejilla de salida con filtro | Rittal | `SK 3243.100` | |
| DIS | 1 | Disipador perfilado 200 mm, Rth 0.3 °C/W | **Fischer Elektronik** | `SK 92 / 200 SA` | los 12 SiC |
| — | 1 | *2.º origen* | Aavid / Boyd | `0S523/200` | |
| FAN2 | 1 | Ventilador axial 24 V 120 mm sobre disipador | **ebm-papst** | `4114 N/2H8P` | |
| — | 1 | Termostato de gabinete NC 60 °C | Rittal | `SK 3110.000` | alarma térmica |
| — | 4 | Separadores M3 hexagonales 15 mm | Würth | `970150151` | montaje de PCB |

## 10. Hallazgos de la simulación que afectan al BOM

Estos puntos **no** son de catálogo: salen de `sim/` y `spice/`.

1. **`Rd` de amortiguamiento del LCL: 6.8 Ω, no 2.2 Ω.**
   Con 2.2 Ω el pico de resonancia queda en 26 dB (inaceptable). Con 6.8 Ω baja
   a 19 dB por 12 W totales. Barrido completo en `sim/run_all.py`.

2. **`dv/dt` medido en SPICE: 147 V/ns.** Lo fija `I_carga / C_oss`, **no** el
   resistor de gate (verificado barriendo `Rg_off` de 6.8 a 47 Ω: sin efecto).
   Dos salidas válidas:
   - **Driver con más CMTI**: `UCC21750` (150 V/ns) en vez de `UCC21520`
     (100 V/ns). **Es la opción recomendada.**
   - **Snubber RC de 220 pF + 4.7 Ω** por rama: baja el `dv/dt` a 90 V/ns y la
     sobretensión de 817 a 767 V, a costa de 10 W en los 12 dispositivos.
     Referencia: KEMET `C0G 220pF 1kV 1210` + Vishay `CRCW25124R70`.

3. **Sobretensión vs inductancia de lazo** (SPICE, doble pulso a 700 V / 30 A):

   | Lazo | Pico | Margen a 1200 V |
   |---:|---:|---|
   | 5 nH | 745 V | holgado |
   | **20 nH** | **817 V** | **objetivo del diseño** |
   | 60 nH | 923 V | justo |
   | 150 nH | 1170 V | **al límite de rotura** |

   Esto justifica numéricamente la regla de layout del floorplan.

4. **Ventilación forzada obligatoria.** 298 W dentro del gabinete; por
   convección natural el interior llegaría a 65 °C. El `SK 3241.100`
   (180 m³/h) da 95 % de margen sobre los 92 m³/h necesarios.

5. **Con el `C3M0075120K` (75 mΩ) de la librería**, `Rth_s-a` baja a
   0.16 °C/W — inviable con aire. **Hay que montar el `C3M0040120K`.**

---

## 11. Normativa aplicable al conjunto montado

| Norma | Qué exige aquí |
|---|---|
| **IEC 61800-5-1** | Seguridad del accionamiento: aislamiento, distancias, descarga del bus < 60 V en < 60 s, ensayo dieléctrico |
| **IEC 61800-3** | EMC del accionamiento (categoría C2 para entorno industrial) |
| **IEC 60204-1** | Equipo eléctrico de máquinas: seta de emergencia, seccionador con enclavamiento, colores de cable, PE |
| **IEEE 519 / IEC 61000-3-12** | THD de corriente de red < 5 % — validado en simulación: **0.09 %** |
| **IEC 60664-1** | Coordinación de aislamiento (las reglas DRC de `kicad/drc_custom_rules.txt`) |
| **IEC 60529** | Grado de protección IP66 del `AE 1180.500` |

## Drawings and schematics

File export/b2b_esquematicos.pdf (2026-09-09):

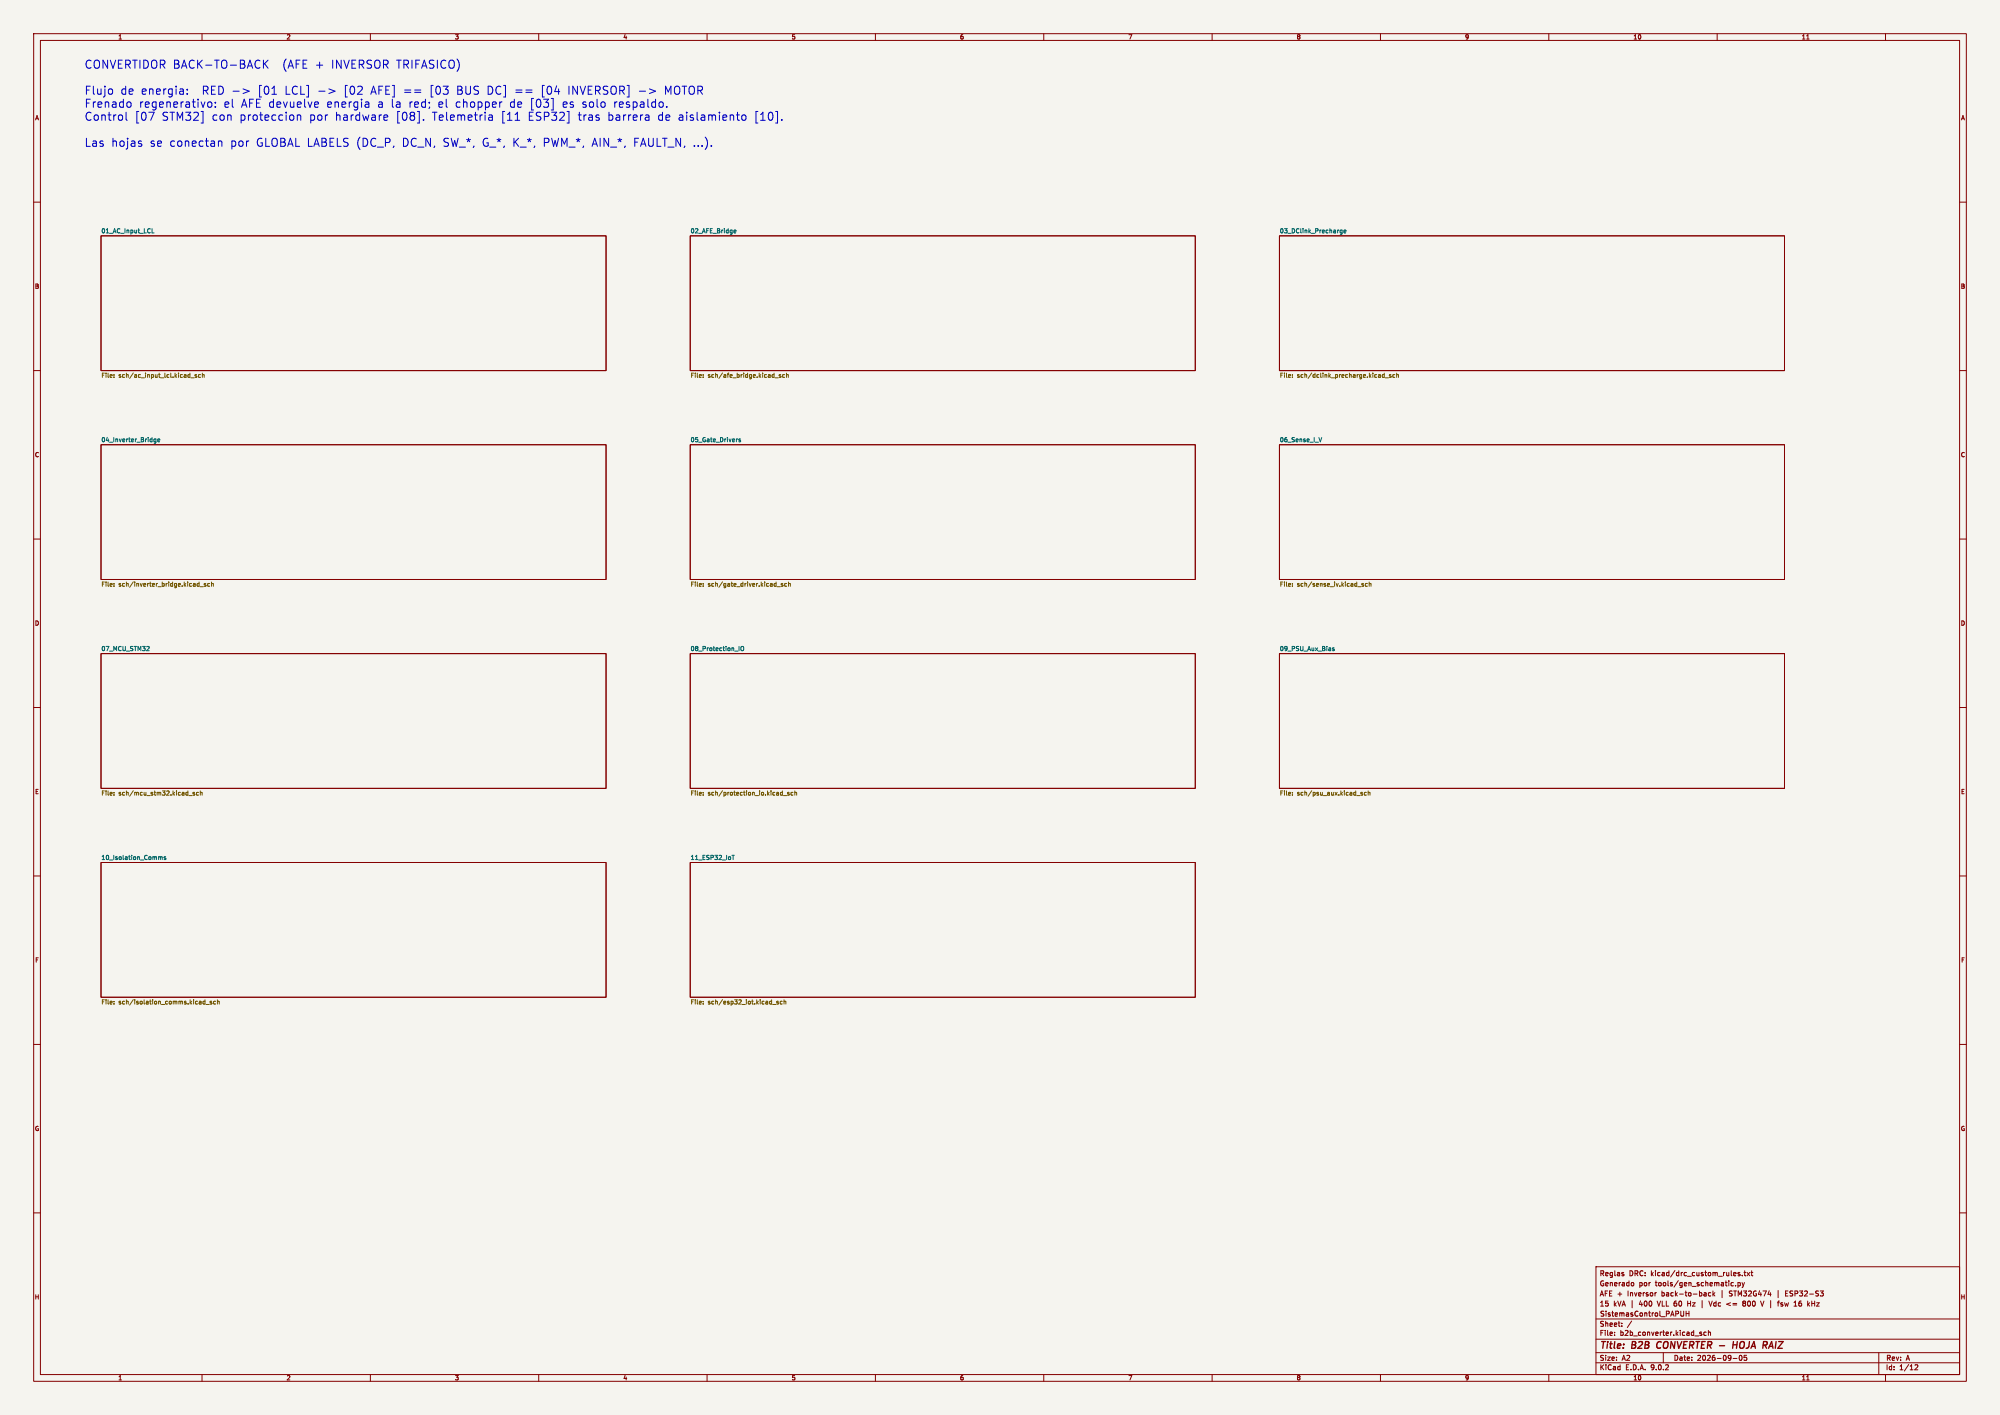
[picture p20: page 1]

Las hojas se conectan por GLOBAL LABELS (DC_P, DC_N, SW_*, G_*, K_*, PWM_*, AIN_*, FAULT_N, ...).

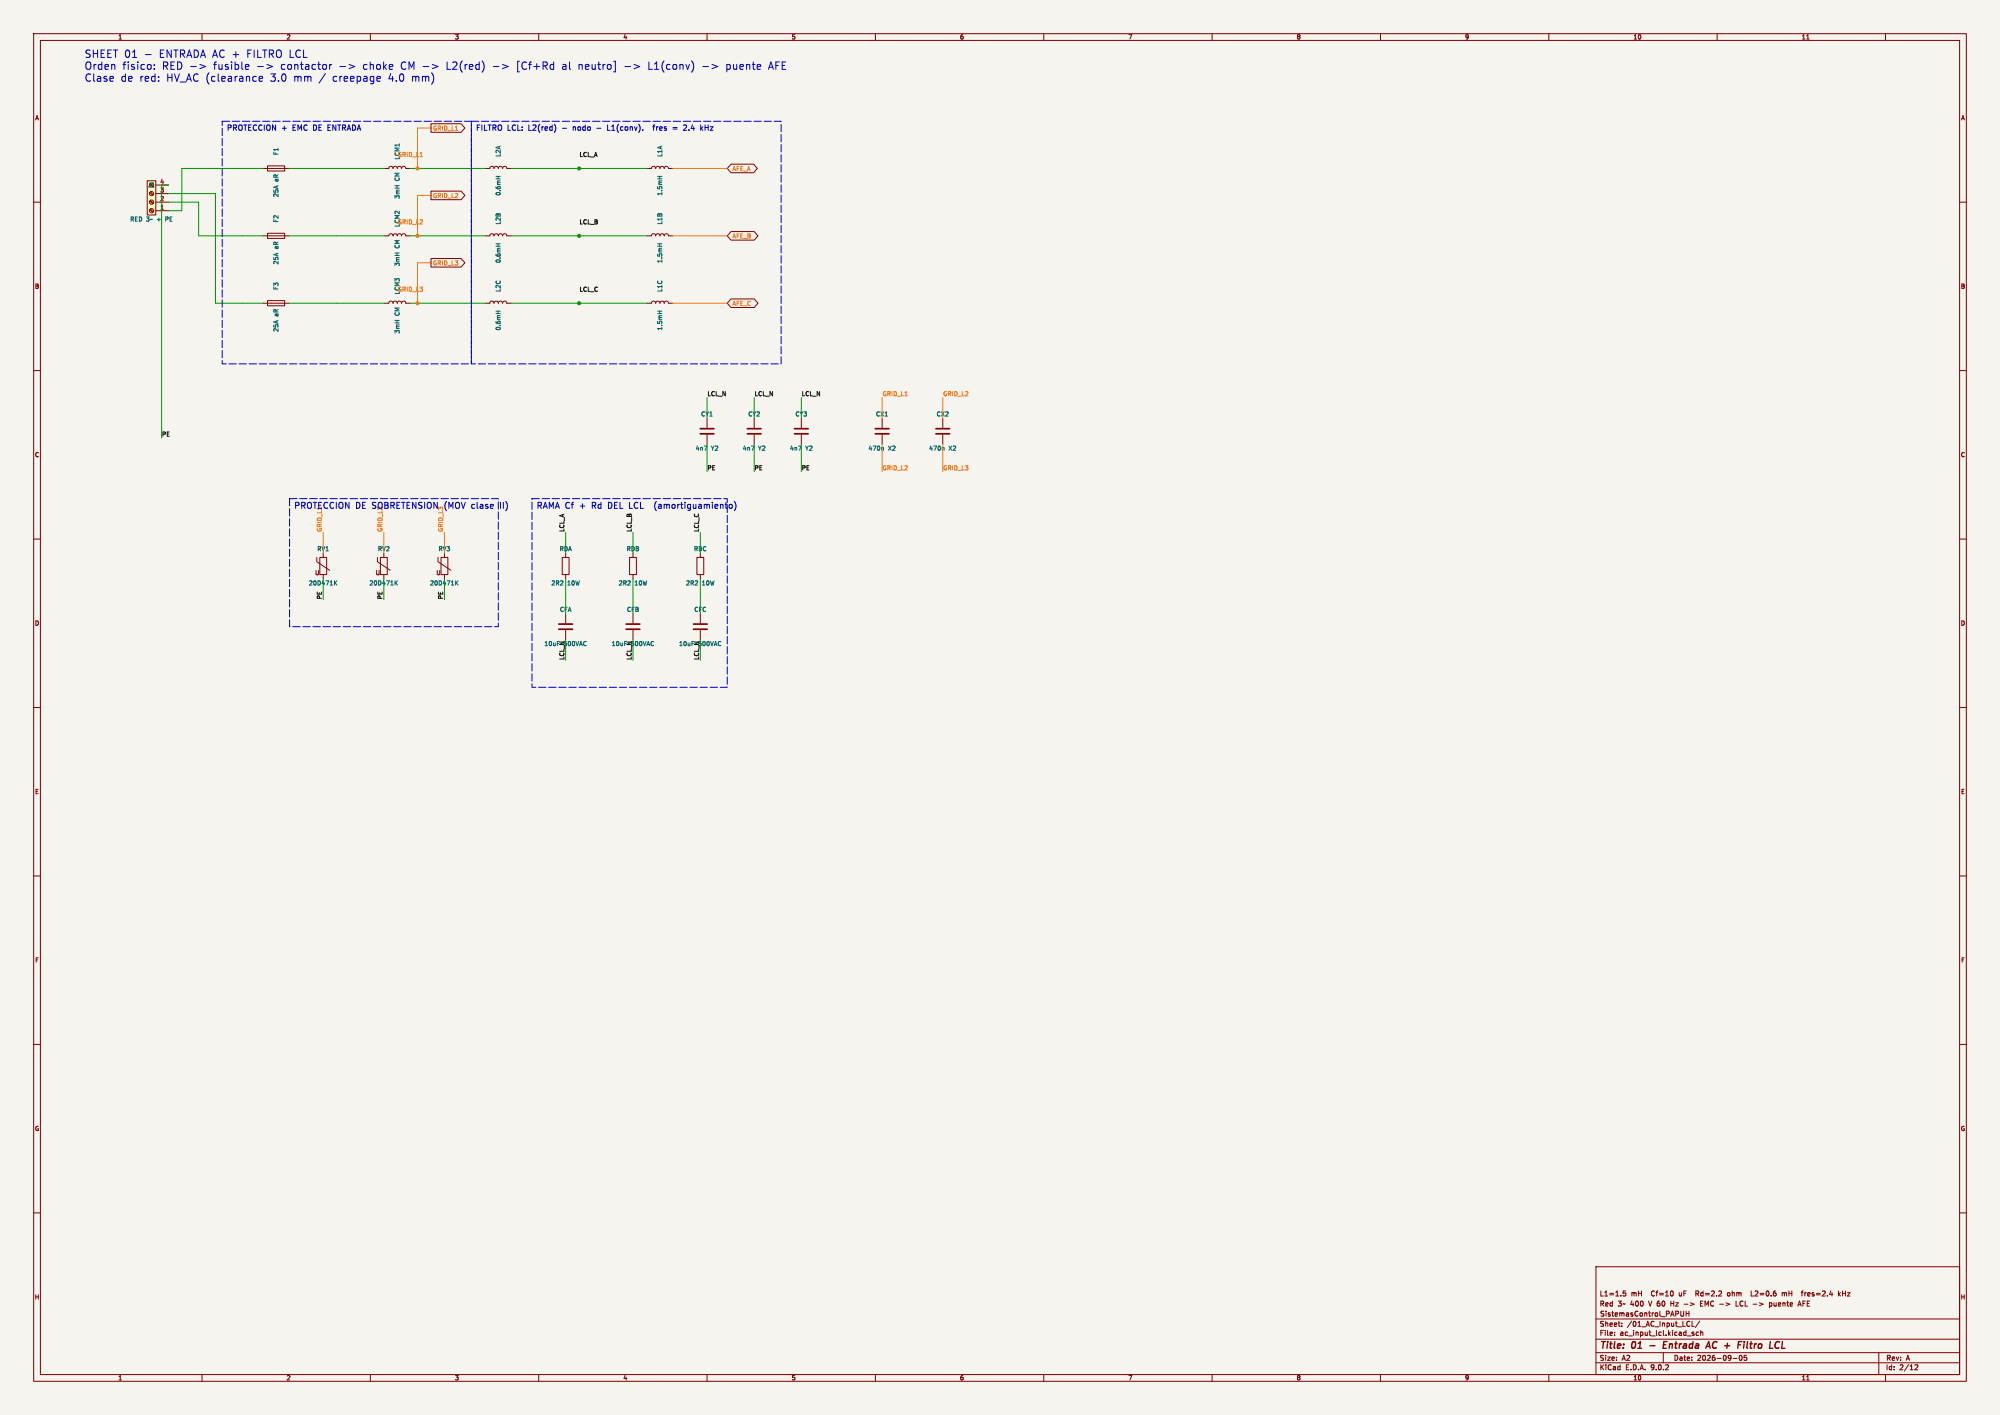
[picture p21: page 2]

SHEET 01 - ENTRADA AC + FILTRO LCL

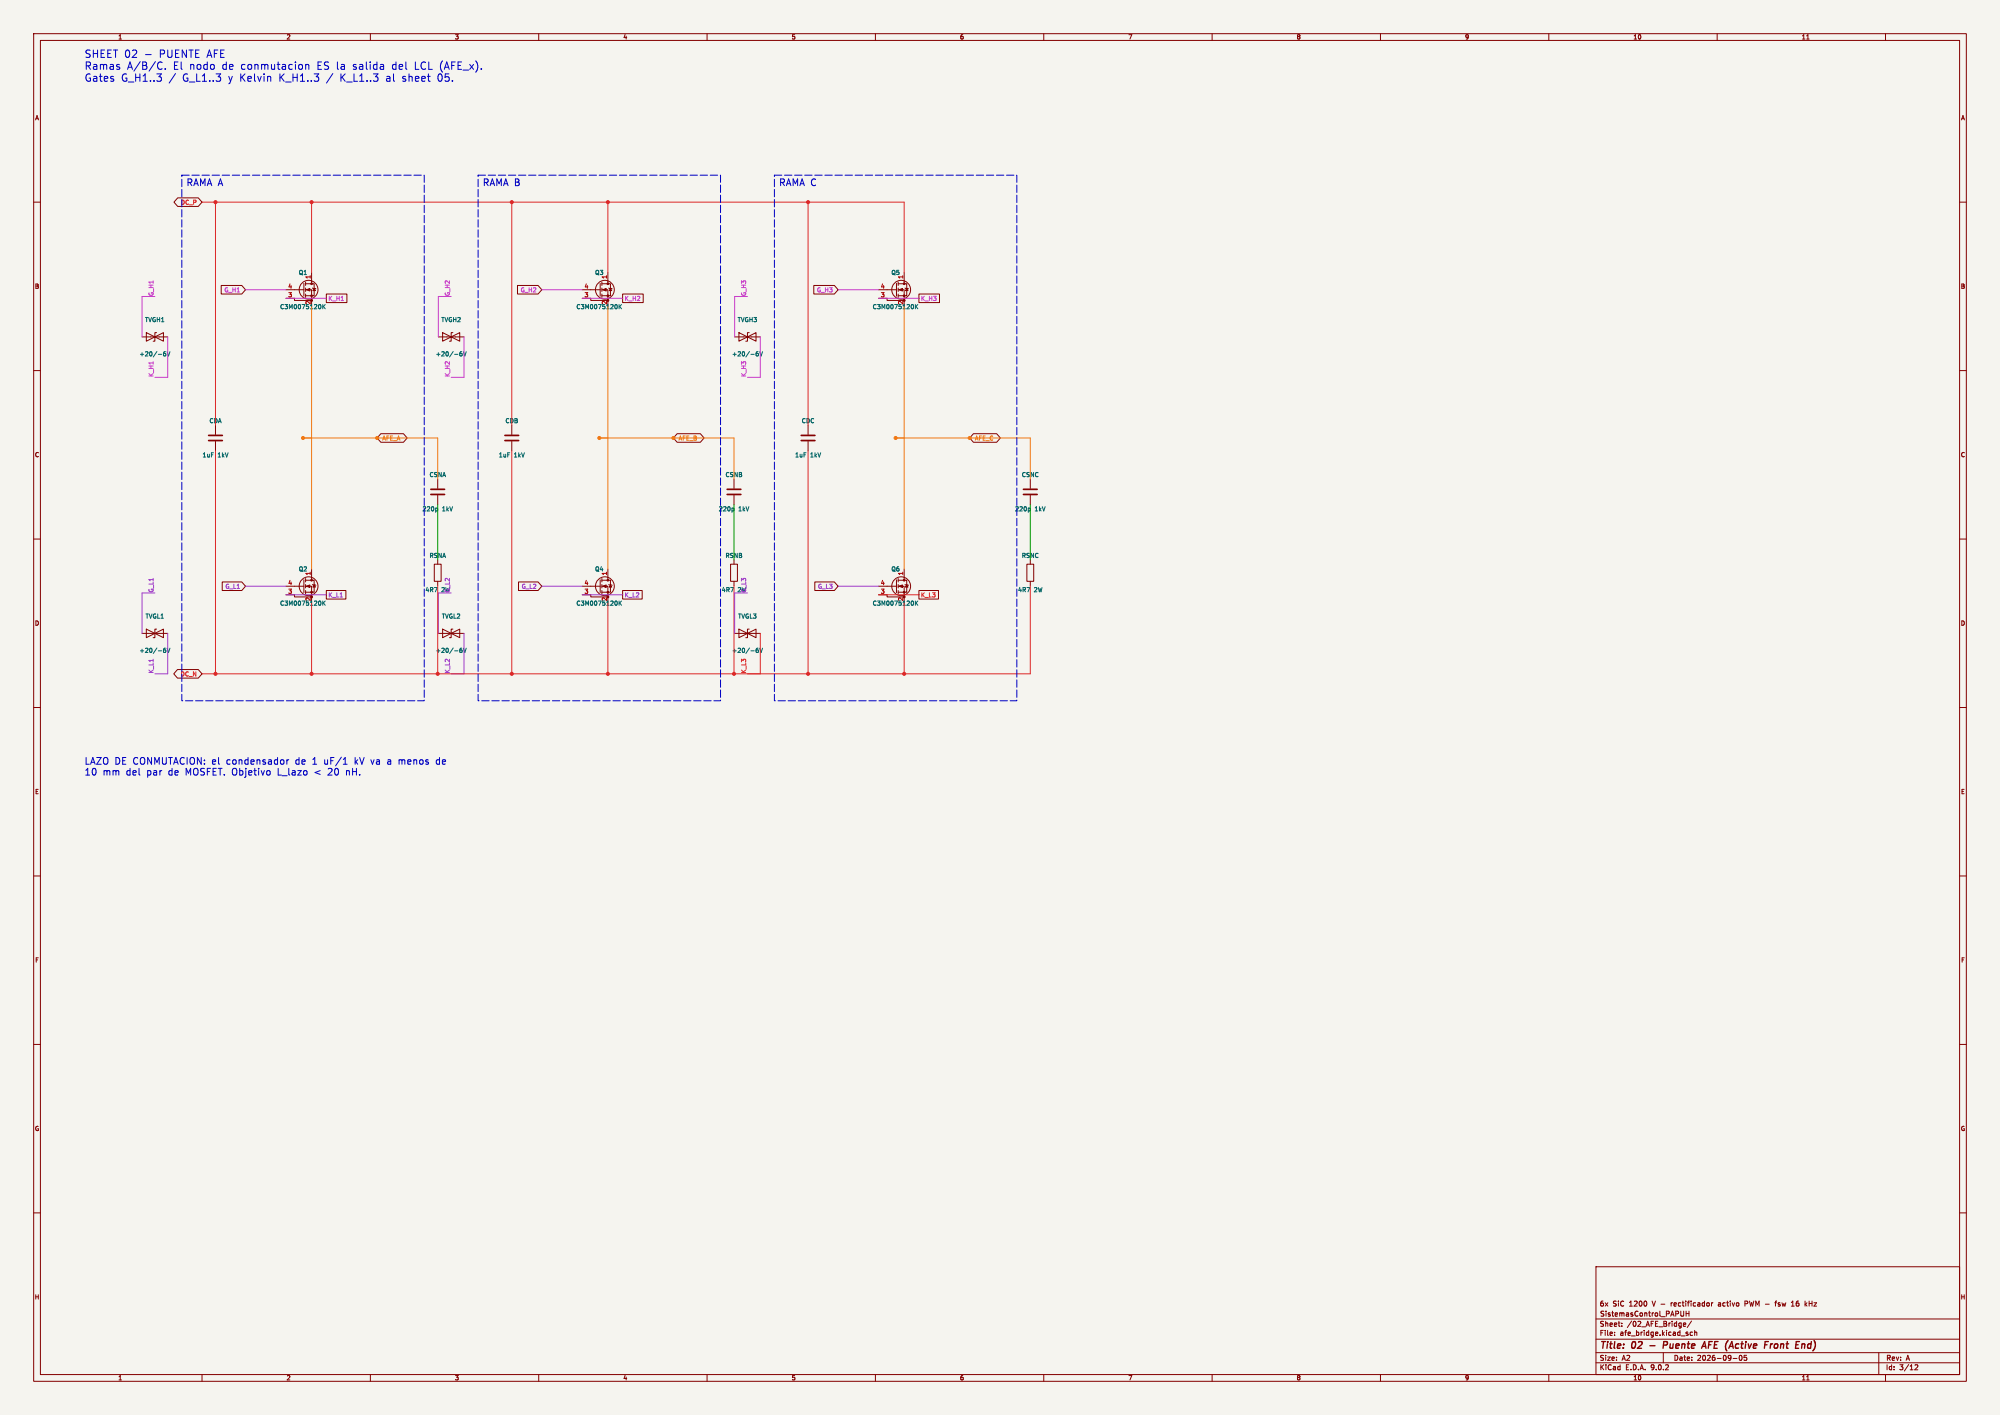
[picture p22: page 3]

SHEET 02 - PUENTE AFE
Gates G_H1..3 / G_L1..3 y Kelvin K_H1..3 / K_L1..3 al sheet 05.

10 mm del par de MOSFET. Objetivo L_lazo < 20 nH.

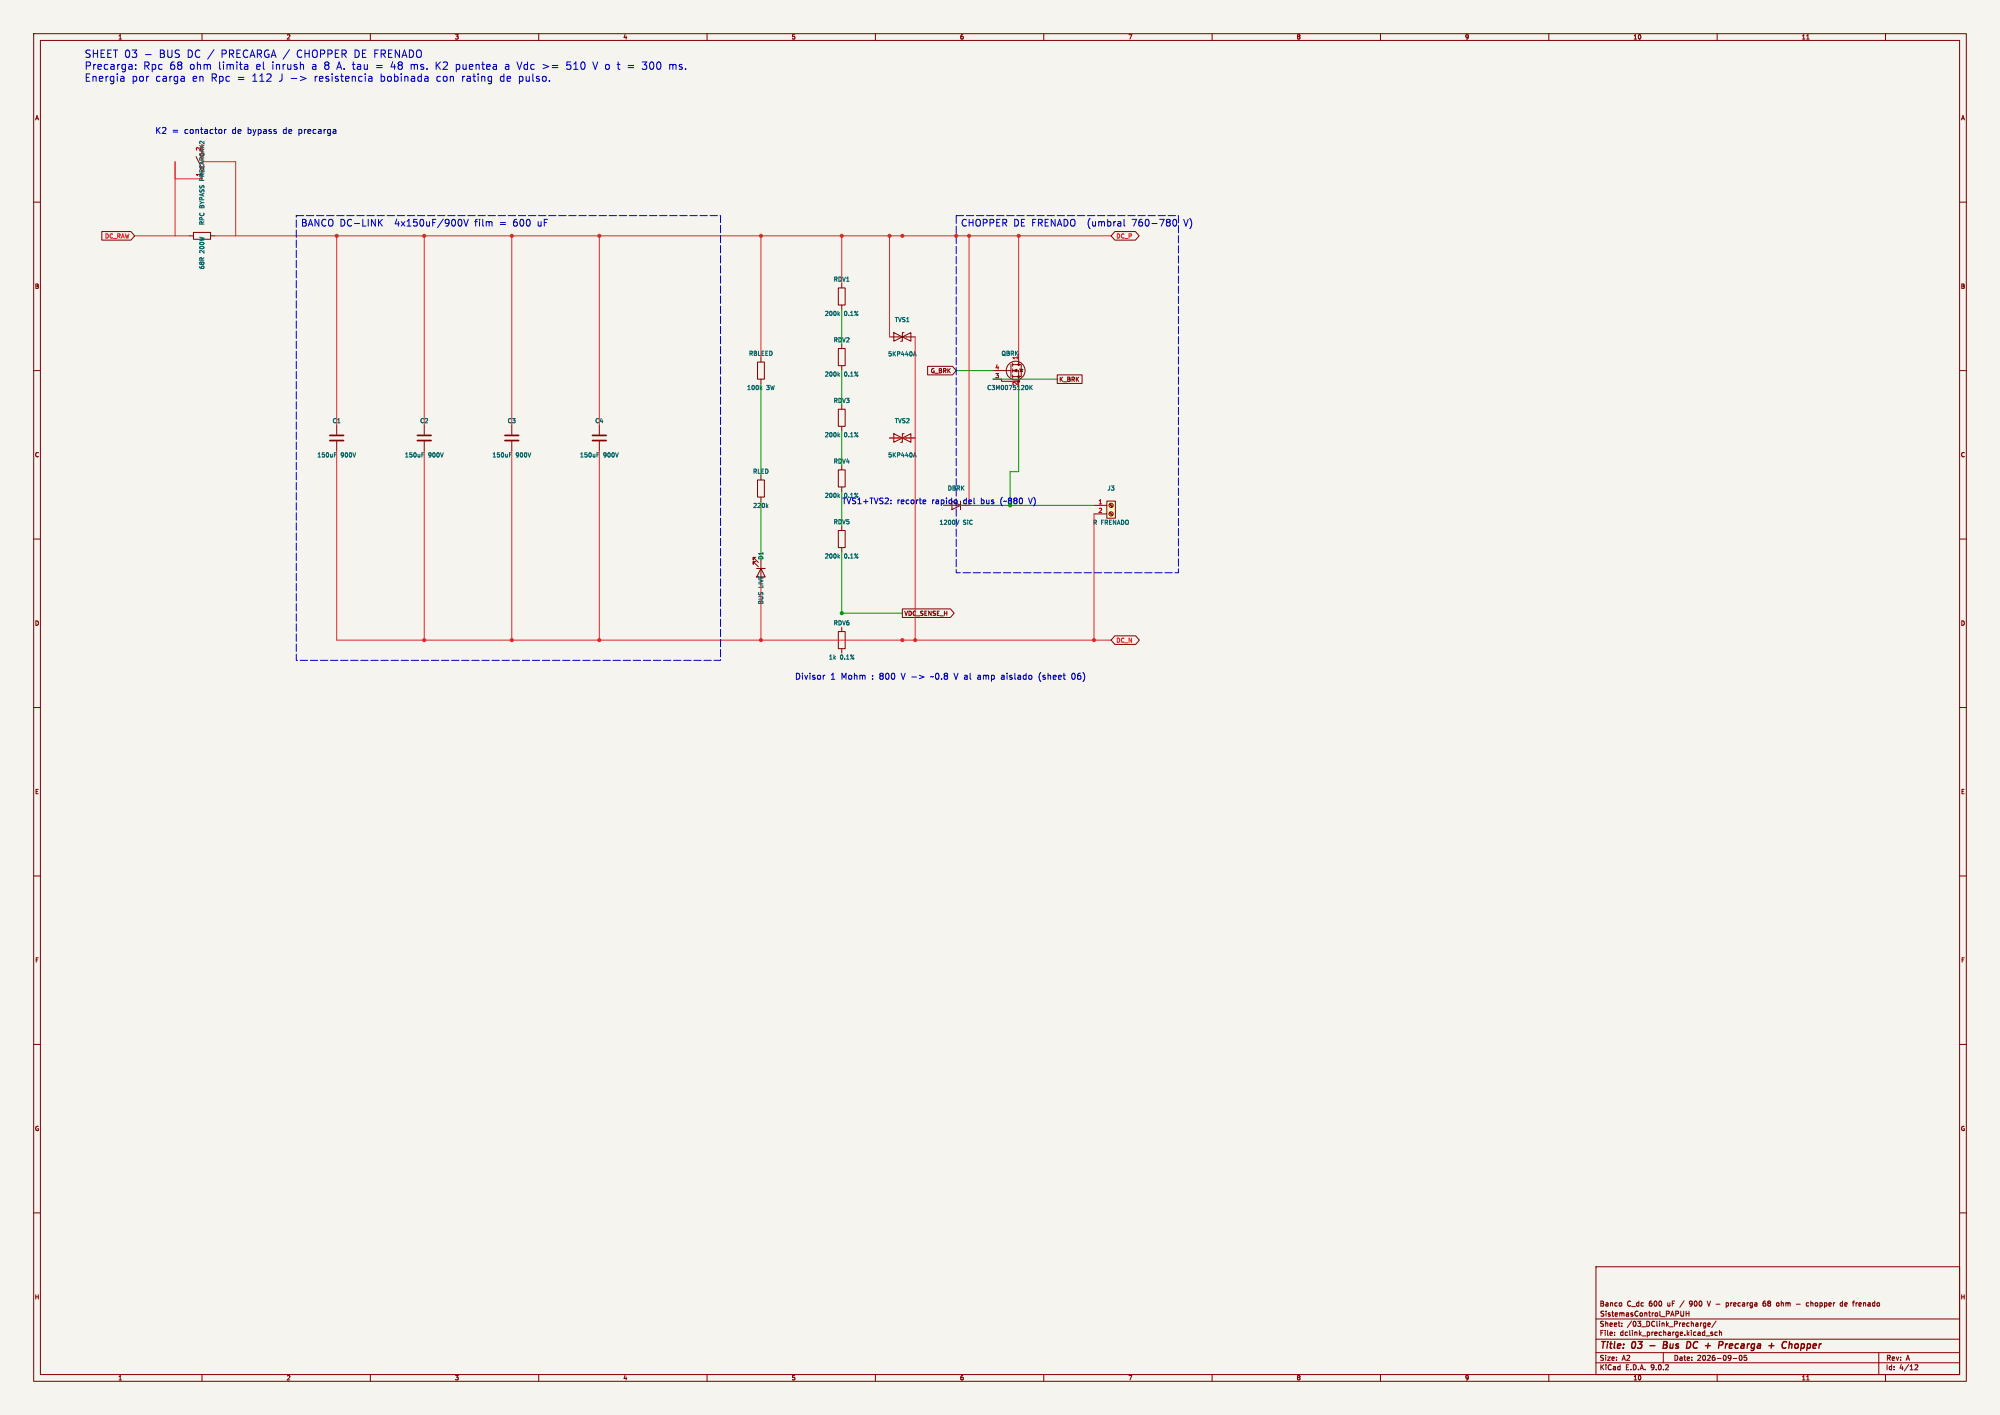
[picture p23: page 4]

DC_P G_BRK SHEET 03 - BUS DC / PRECARGA / CHOPPER DE FRENADO
Precarga: Rpc 68 ohm limita el inrush a 8 A. tau = 48 ms. K2 puentea a Vdc >= 510 V o t = 300 ms.

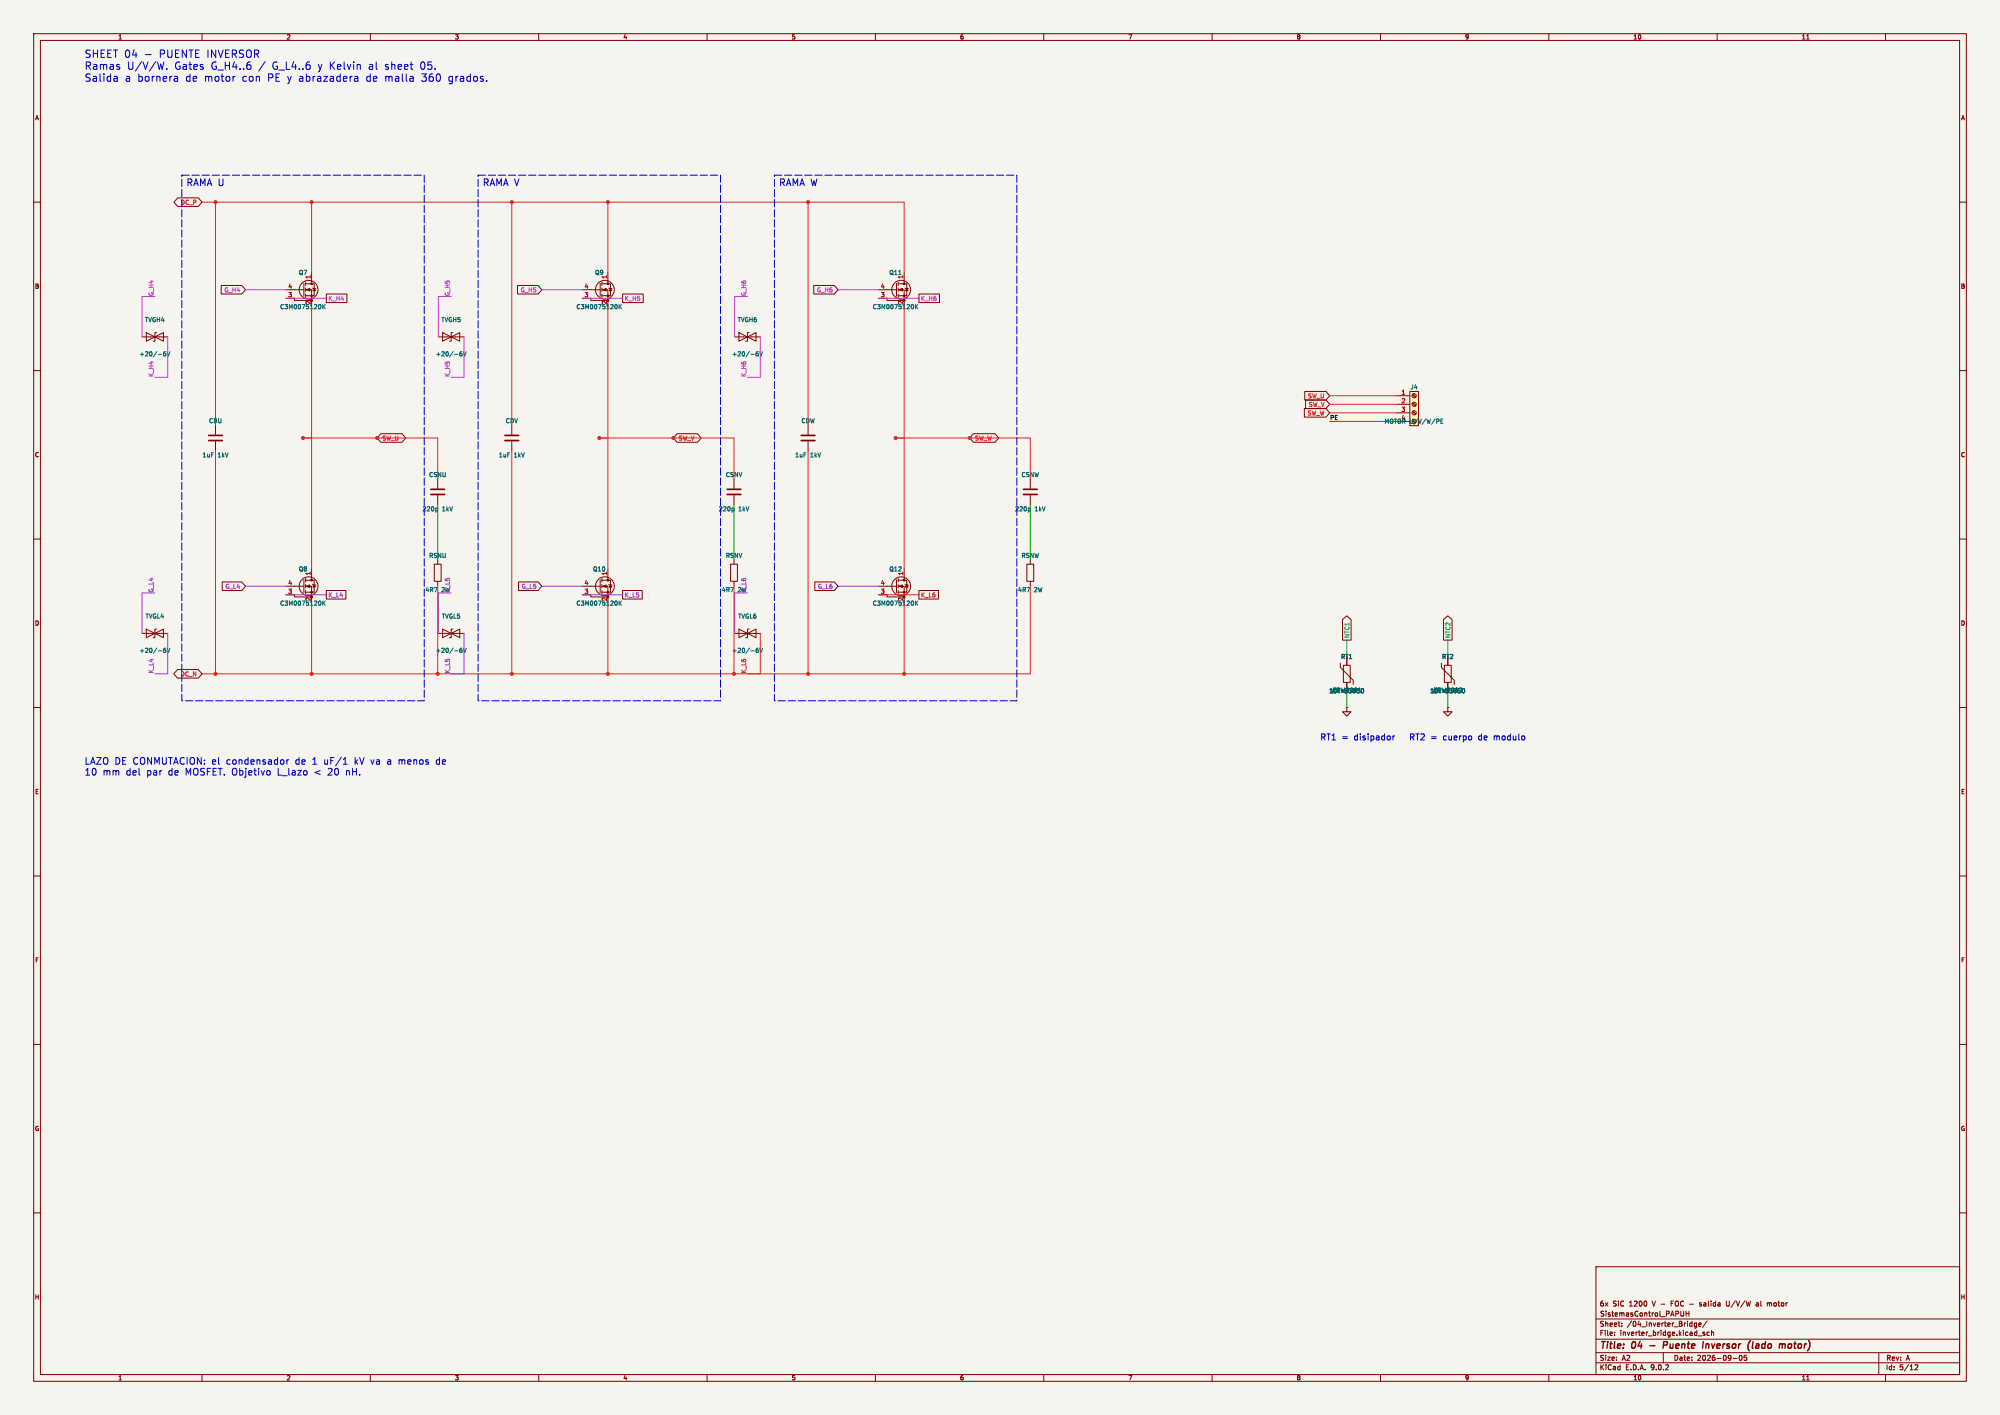
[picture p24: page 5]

10 mm del par de MOSFET. Objetivo L_lazo < 20 nH.

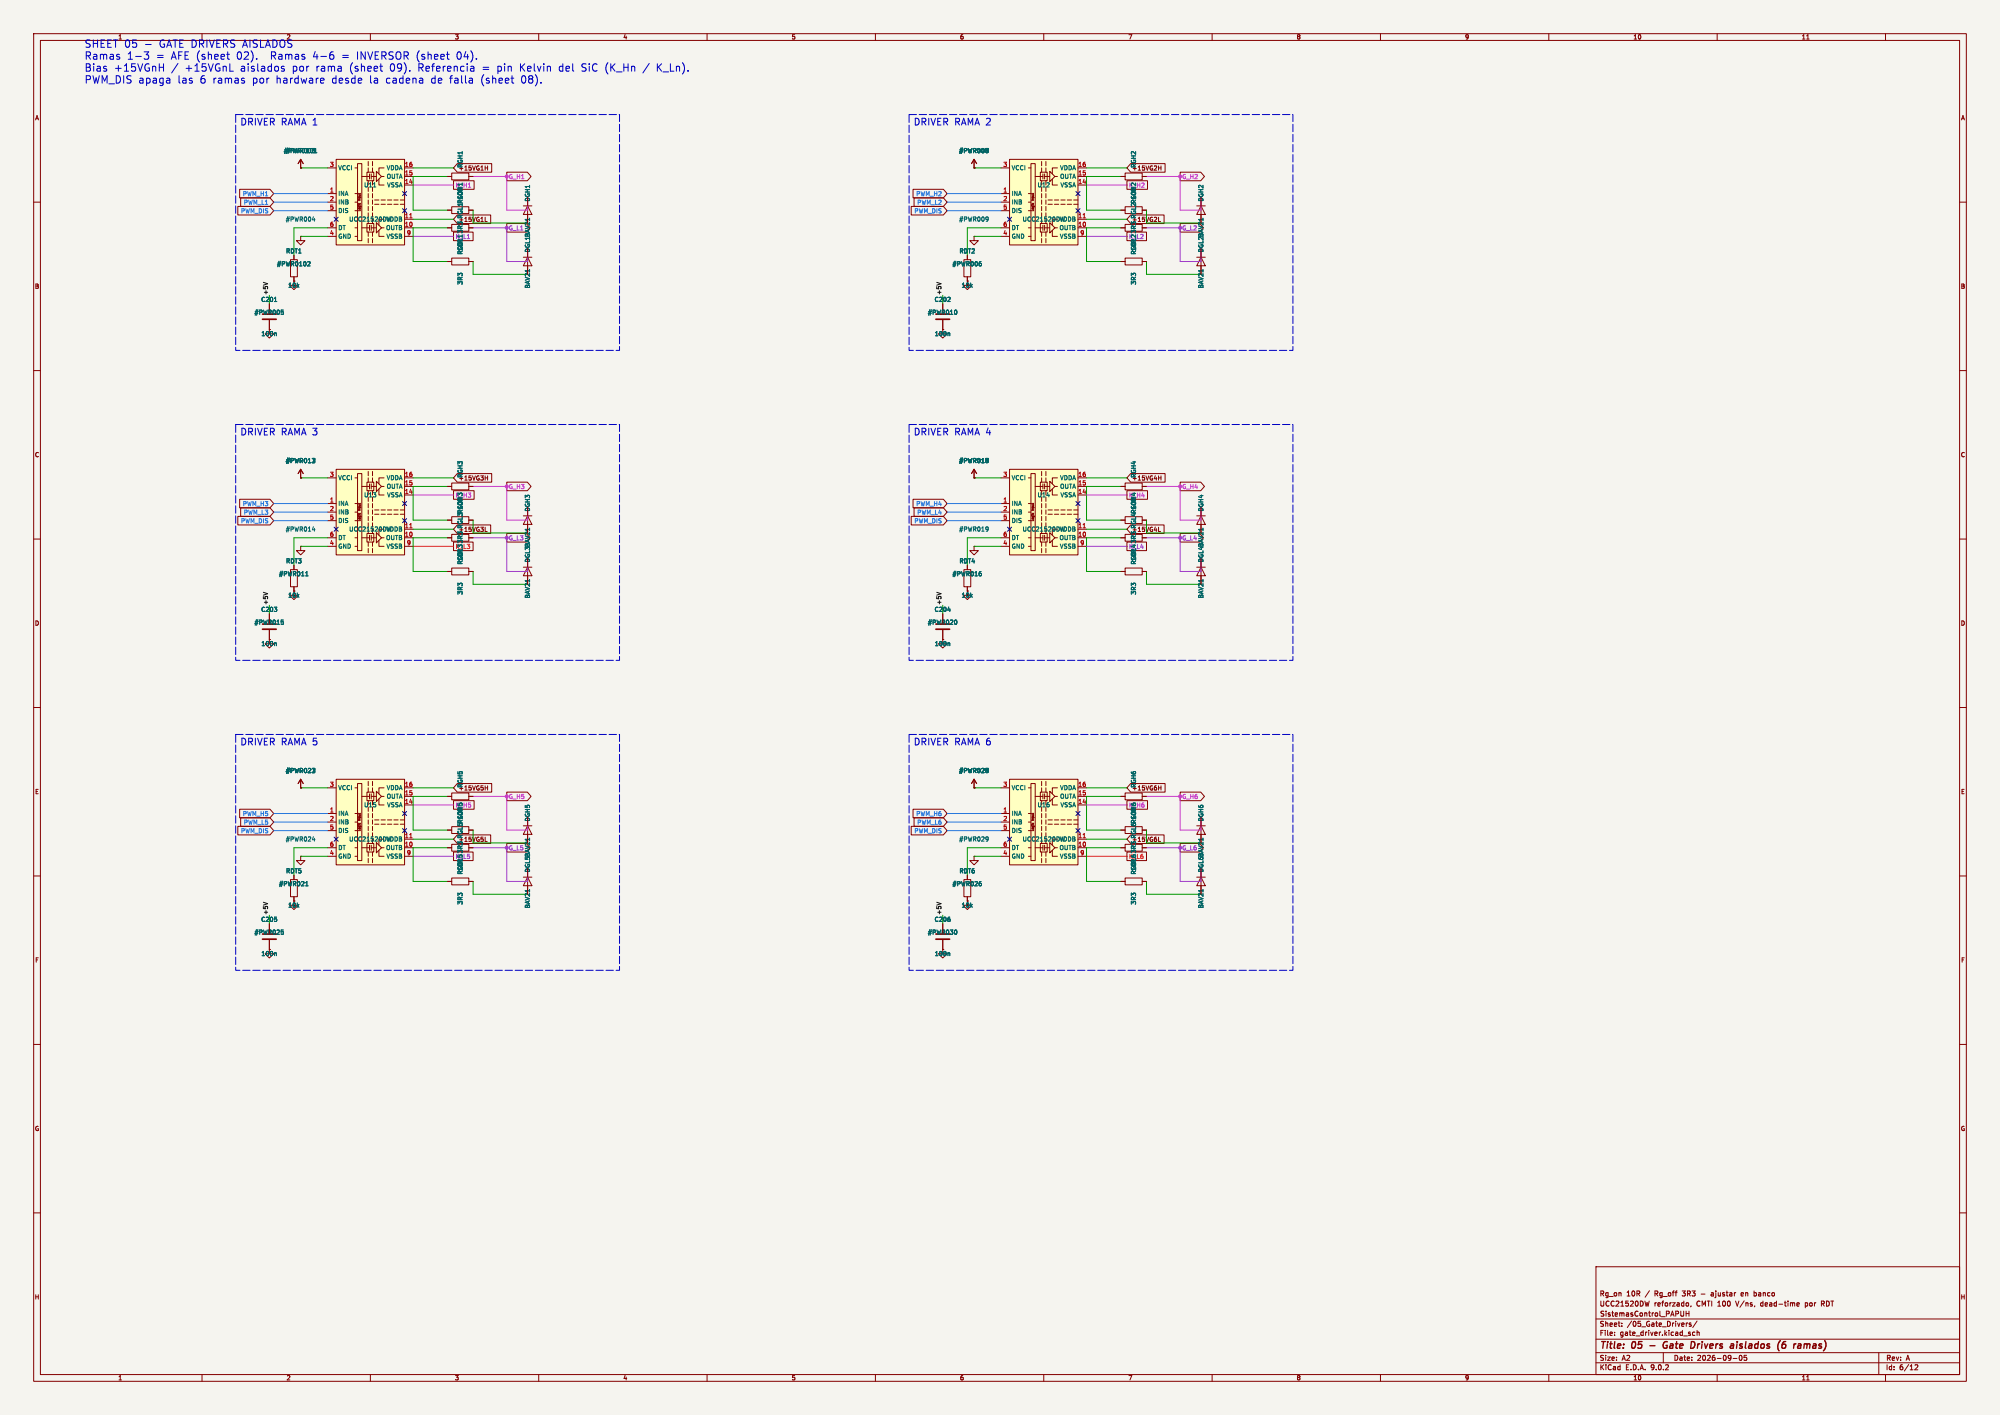
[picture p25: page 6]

SHEET 05 - GATE DRIVERS AISLADOS
Bias +15VGnH / +15VGnL aislados por rama (sheet 09). Referencia = pin Kelvin del SiC (K_Hn / K_Ln).
PWM_DIS apaga las 6 ramas por hardware desde la cadena de falla (sheet 08).

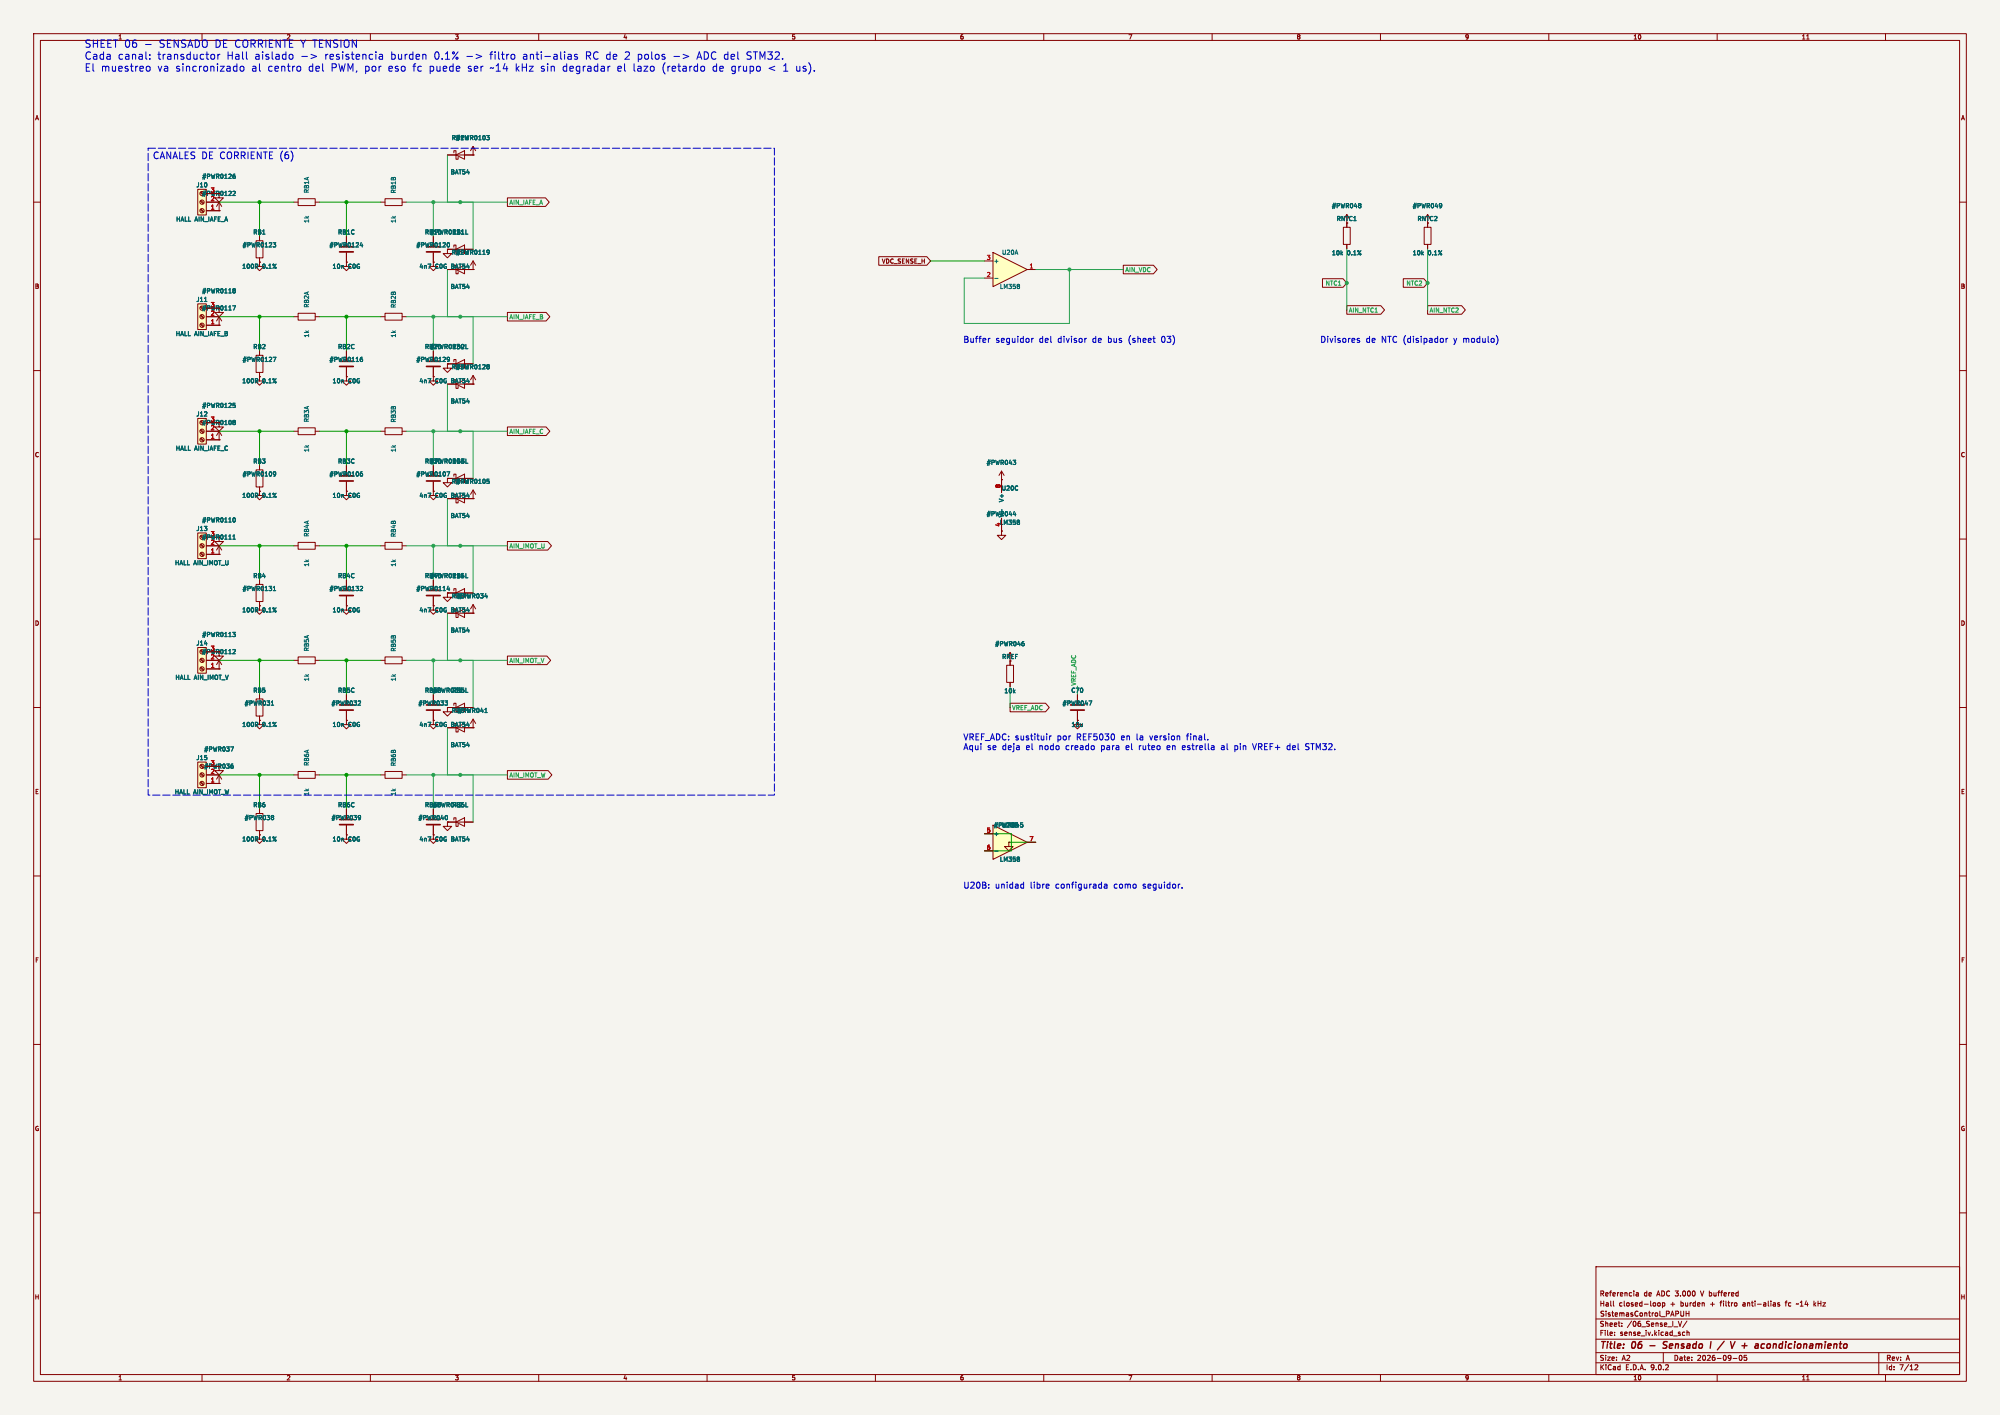
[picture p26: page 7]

Buffer seguidor del divisor de bus (sheet 03)

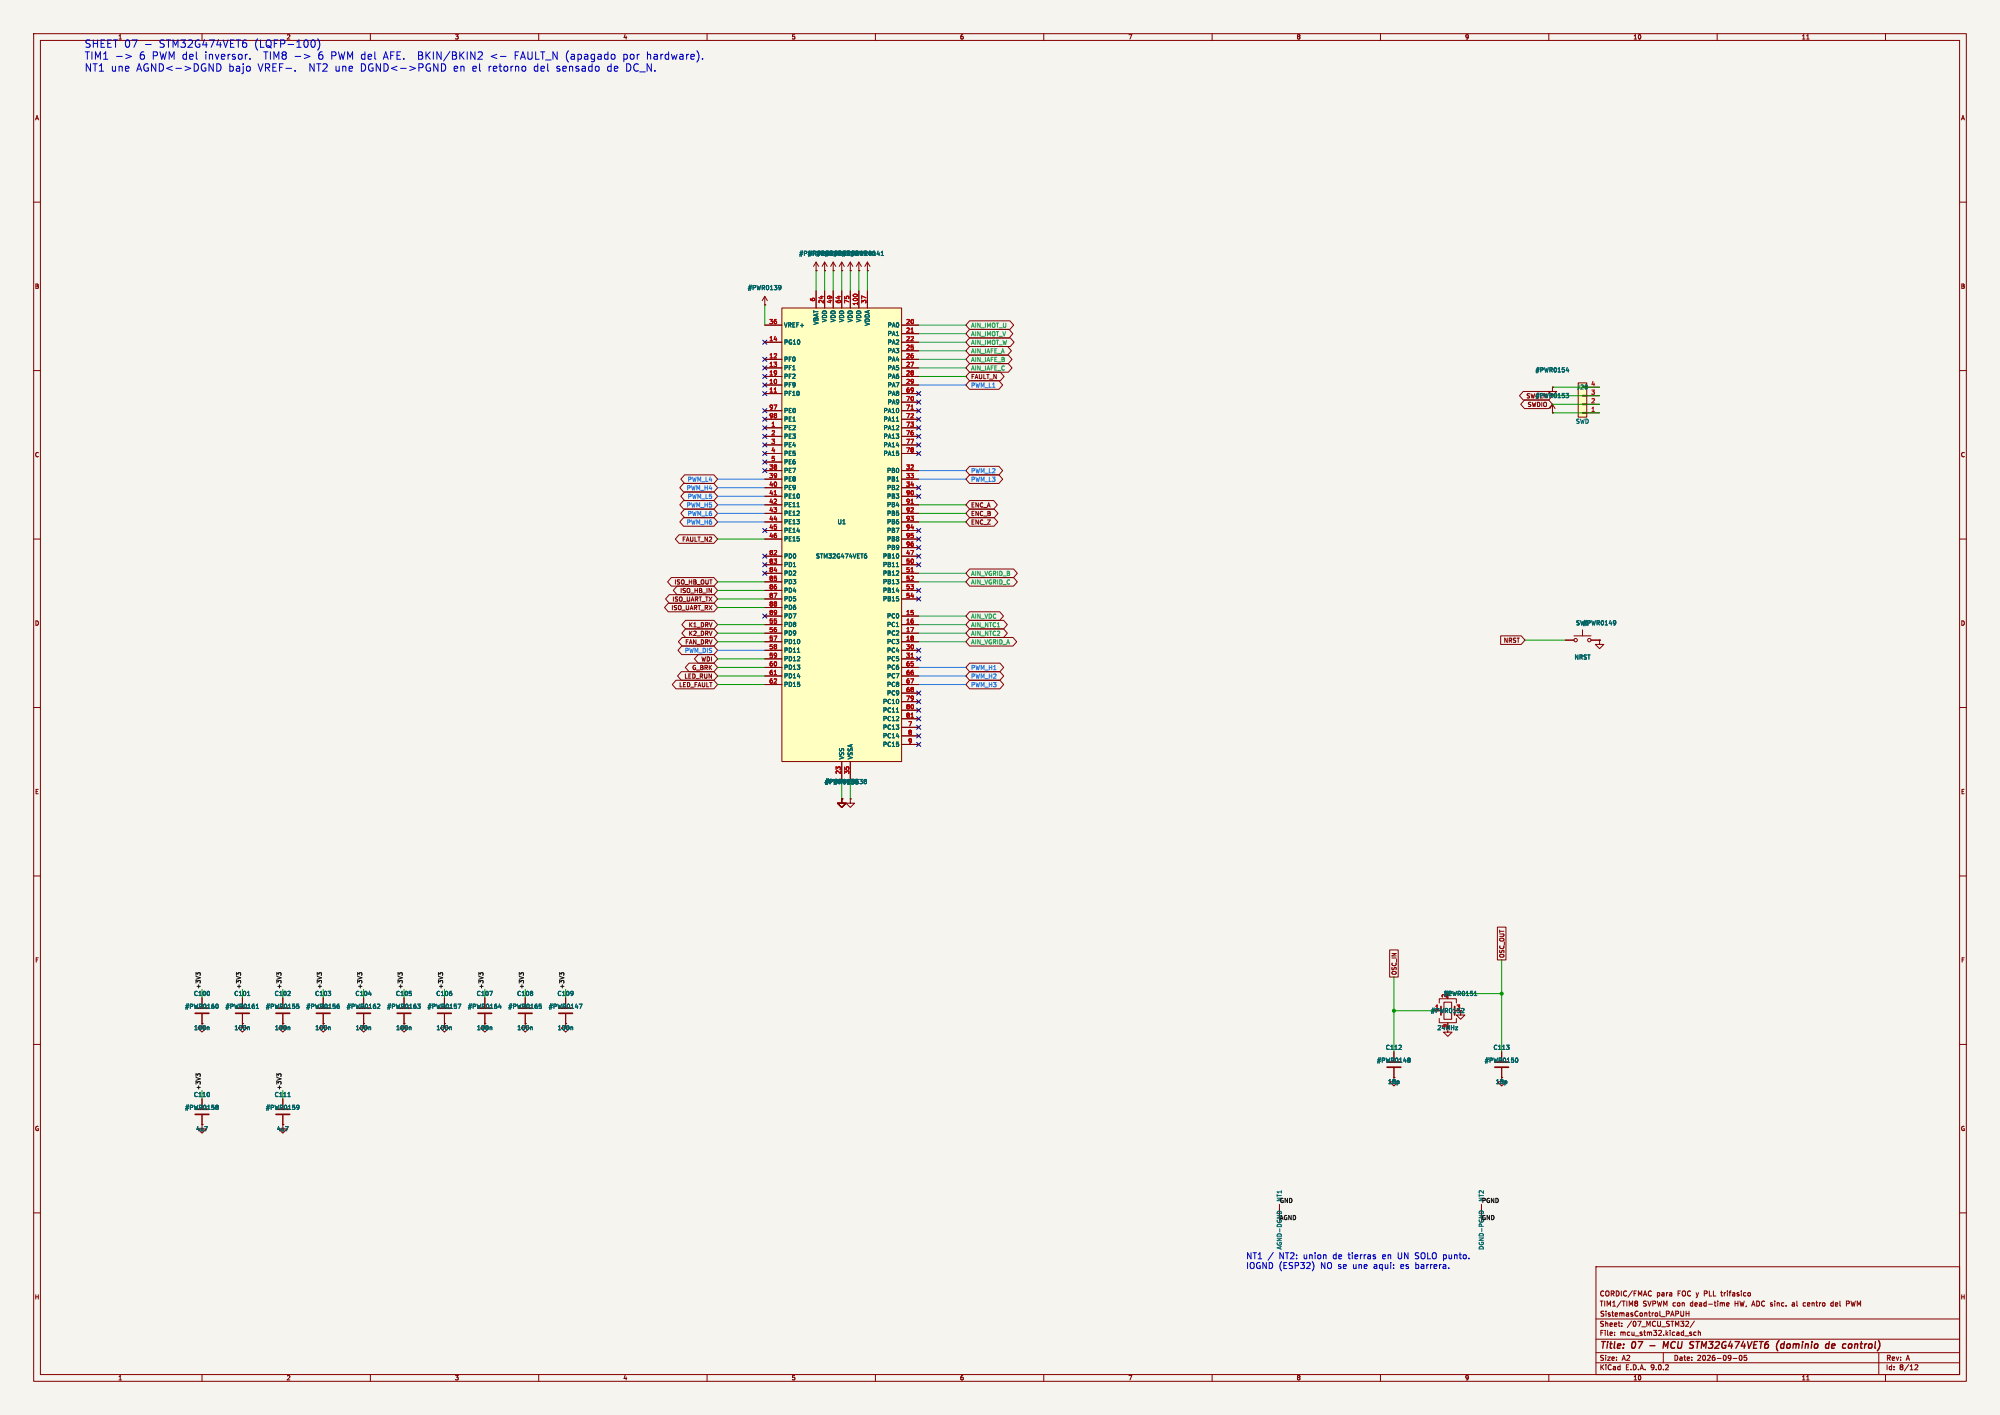
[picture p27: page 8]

6 VDD 24 VDD 49 VDD 64 VSS 23 VDD 75 VSSA 35 VDD 100 VDDA 37 PA0 20 PA1 21 PA2 22 PA3 25 PA4 26 PA5 27 PA6 28 PA7 29 PA8 69 PA9 70 PA10 71 PA11 72 PA12 73 PA13 76 PA14 77 PA15 78 PB0 32 PB1 33 PB2 34 PB3 90 PB4 91 PB5 92 PB6 93 PB7 94 PB8 95 PB9 96 PB10 47 PB11 50 PB12 51 PB13 52 PB14 53 PB15 54 PC0 15 PC1 16 PC2 17 PC3 18 PC4 30 PC5 31 PC6 65 PC7 66 PC8 67 PC9 68 PC10 79 PC11 80 PC12 81 PC13 7 PC14 8 PC15 9 U1 STM32G474VET6

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

NT1 / NT2: union de tierras en UN SOLO punto.
IOGND (ESP32) NO se une aqui: es barrera.

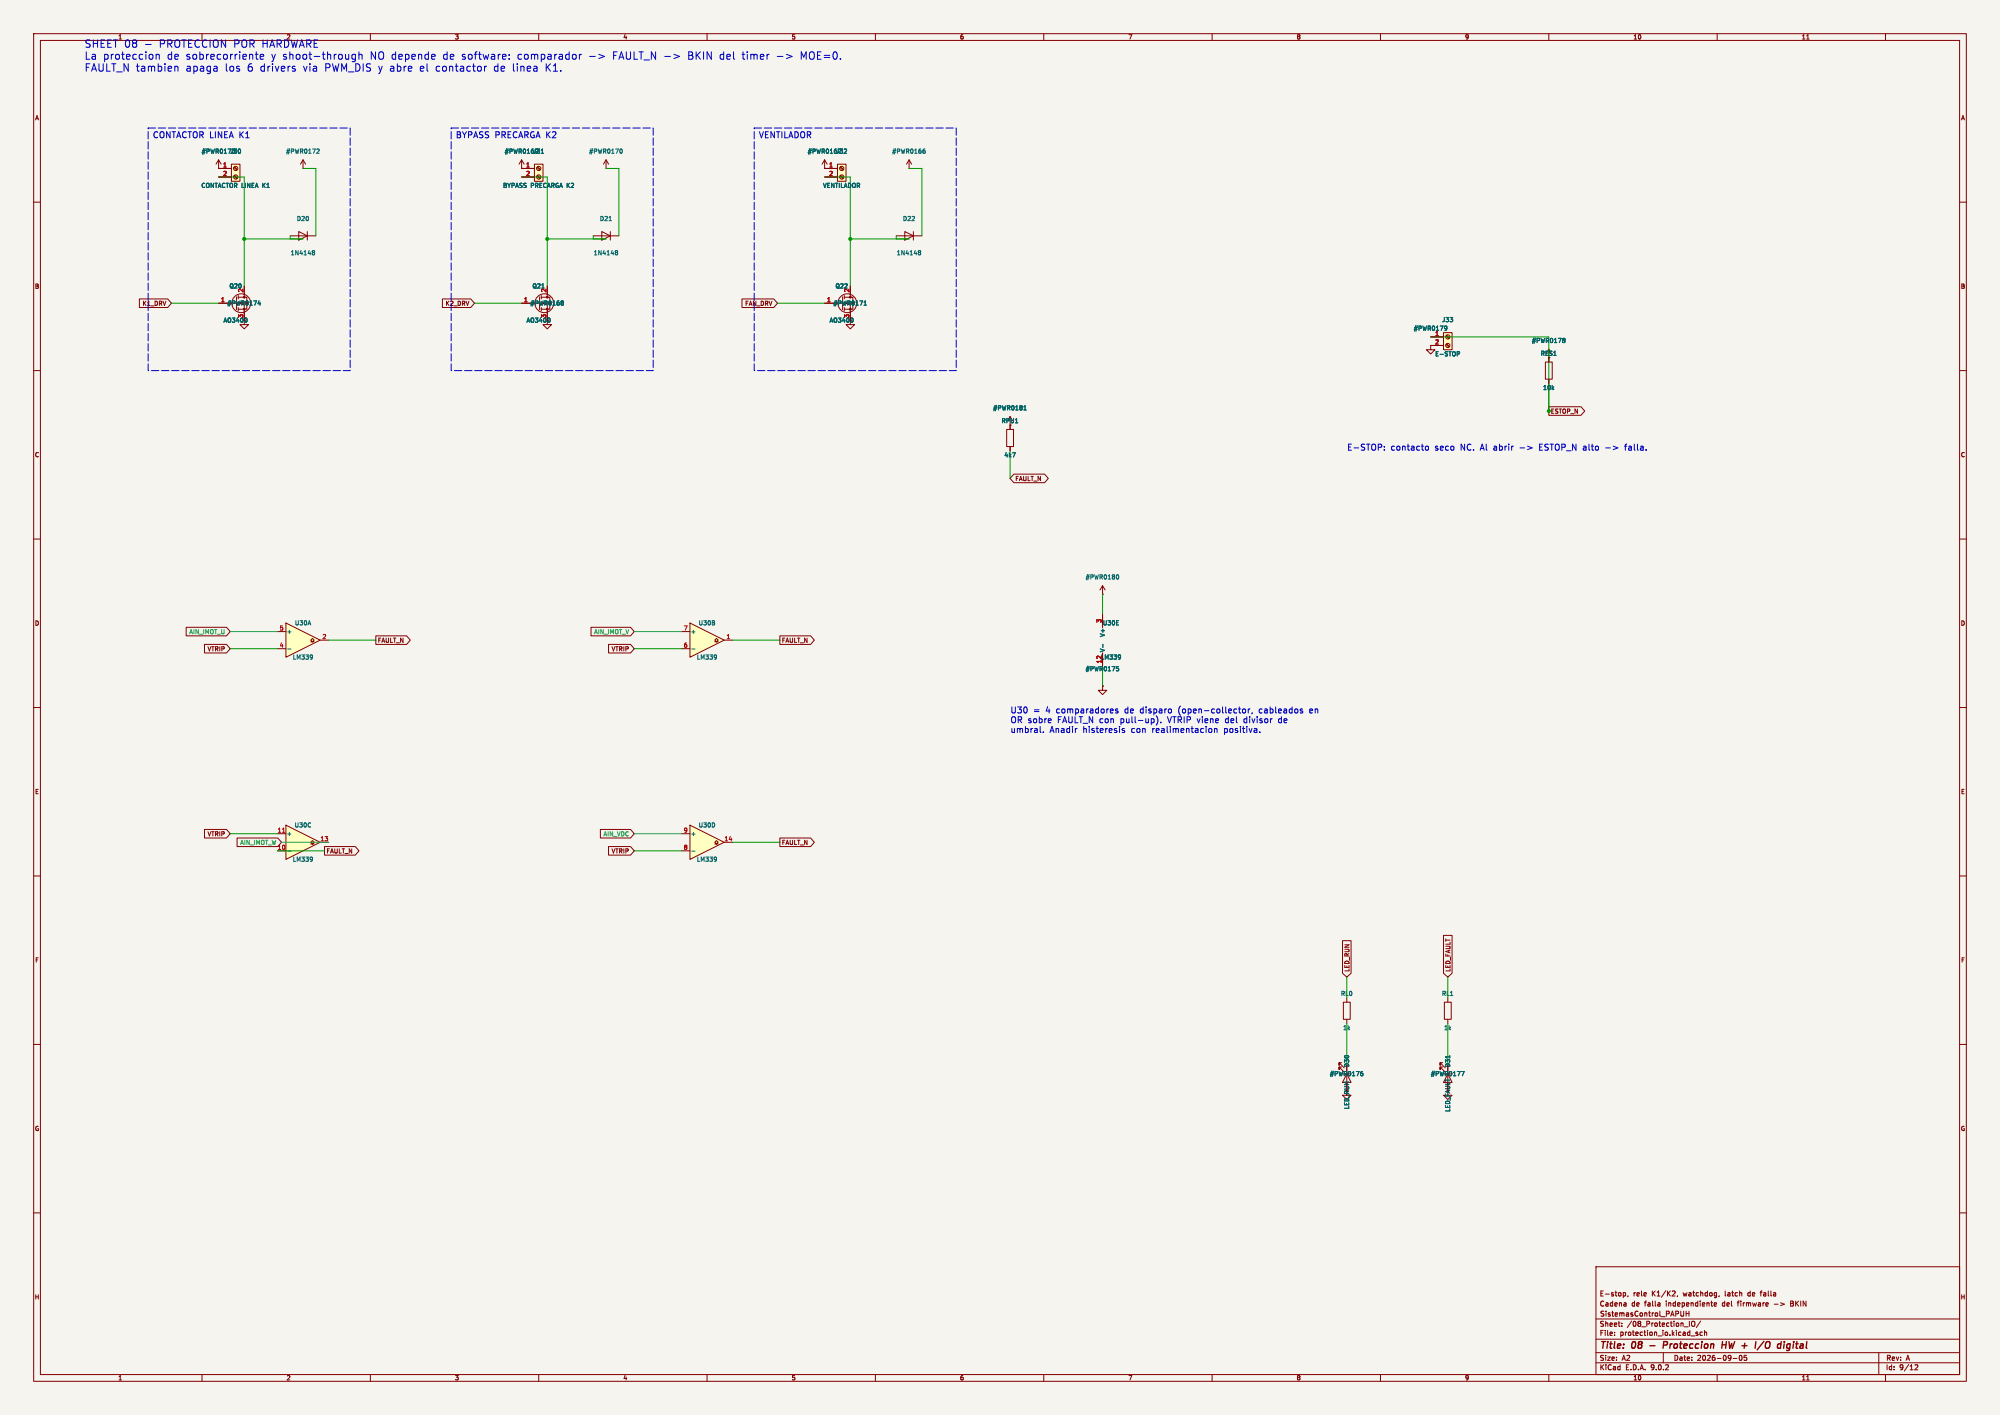
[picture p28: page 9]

SHEET 08 - PROTECCION POR HARDWARE

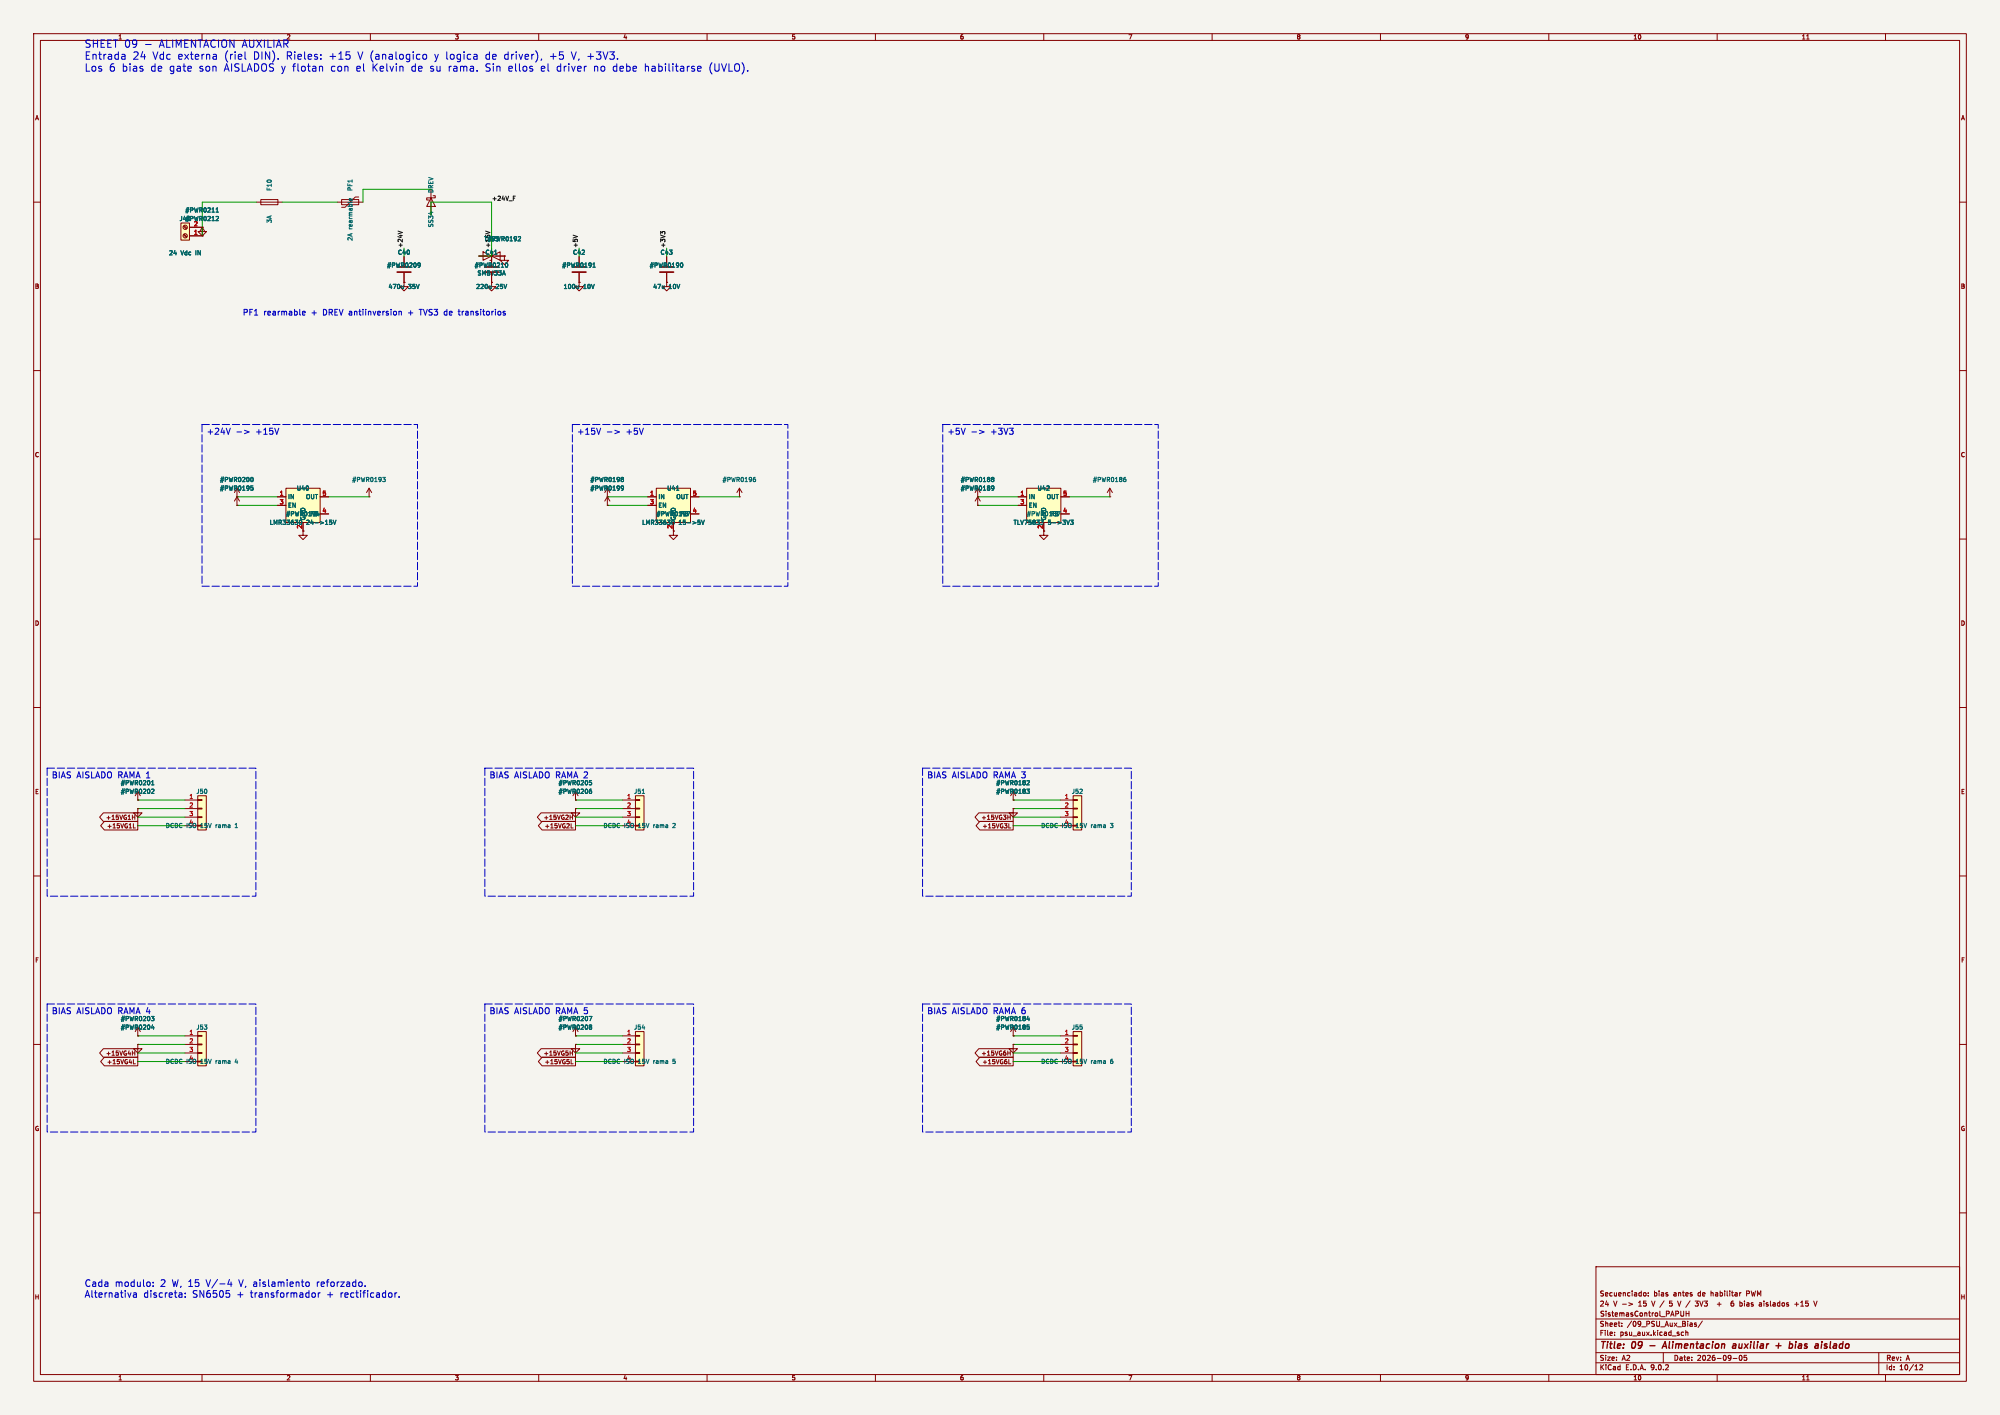
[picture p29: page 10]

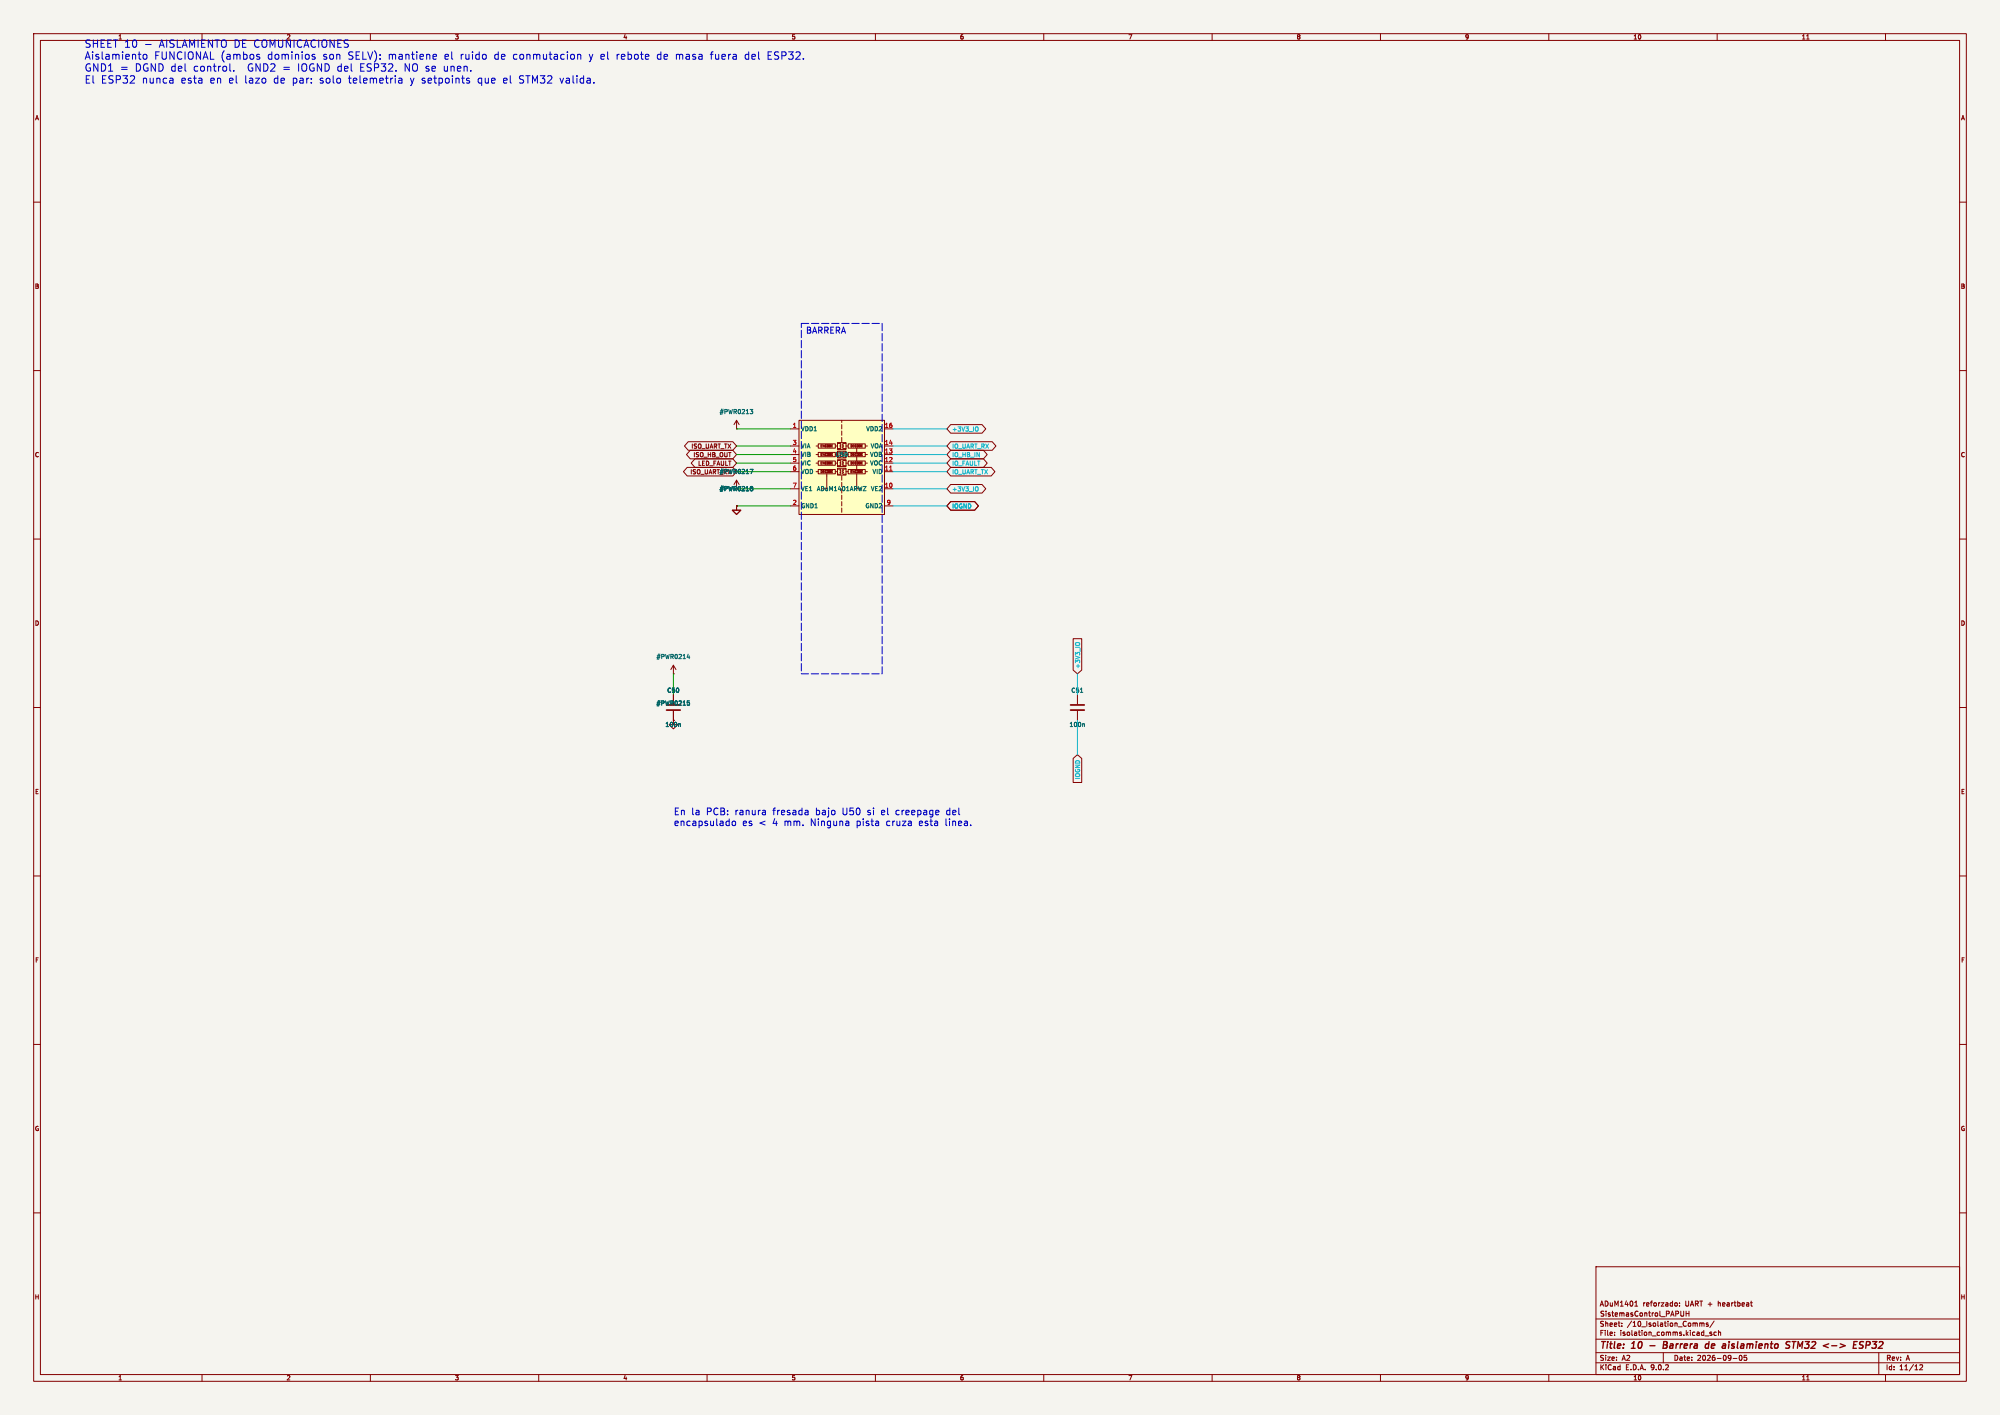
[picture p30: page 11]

ISO_UART_TX SHEET 10 - AISLAMIENTO DE COMUNICACIONES

En la PCB: ranura fresada bajo U50 si el creepage del

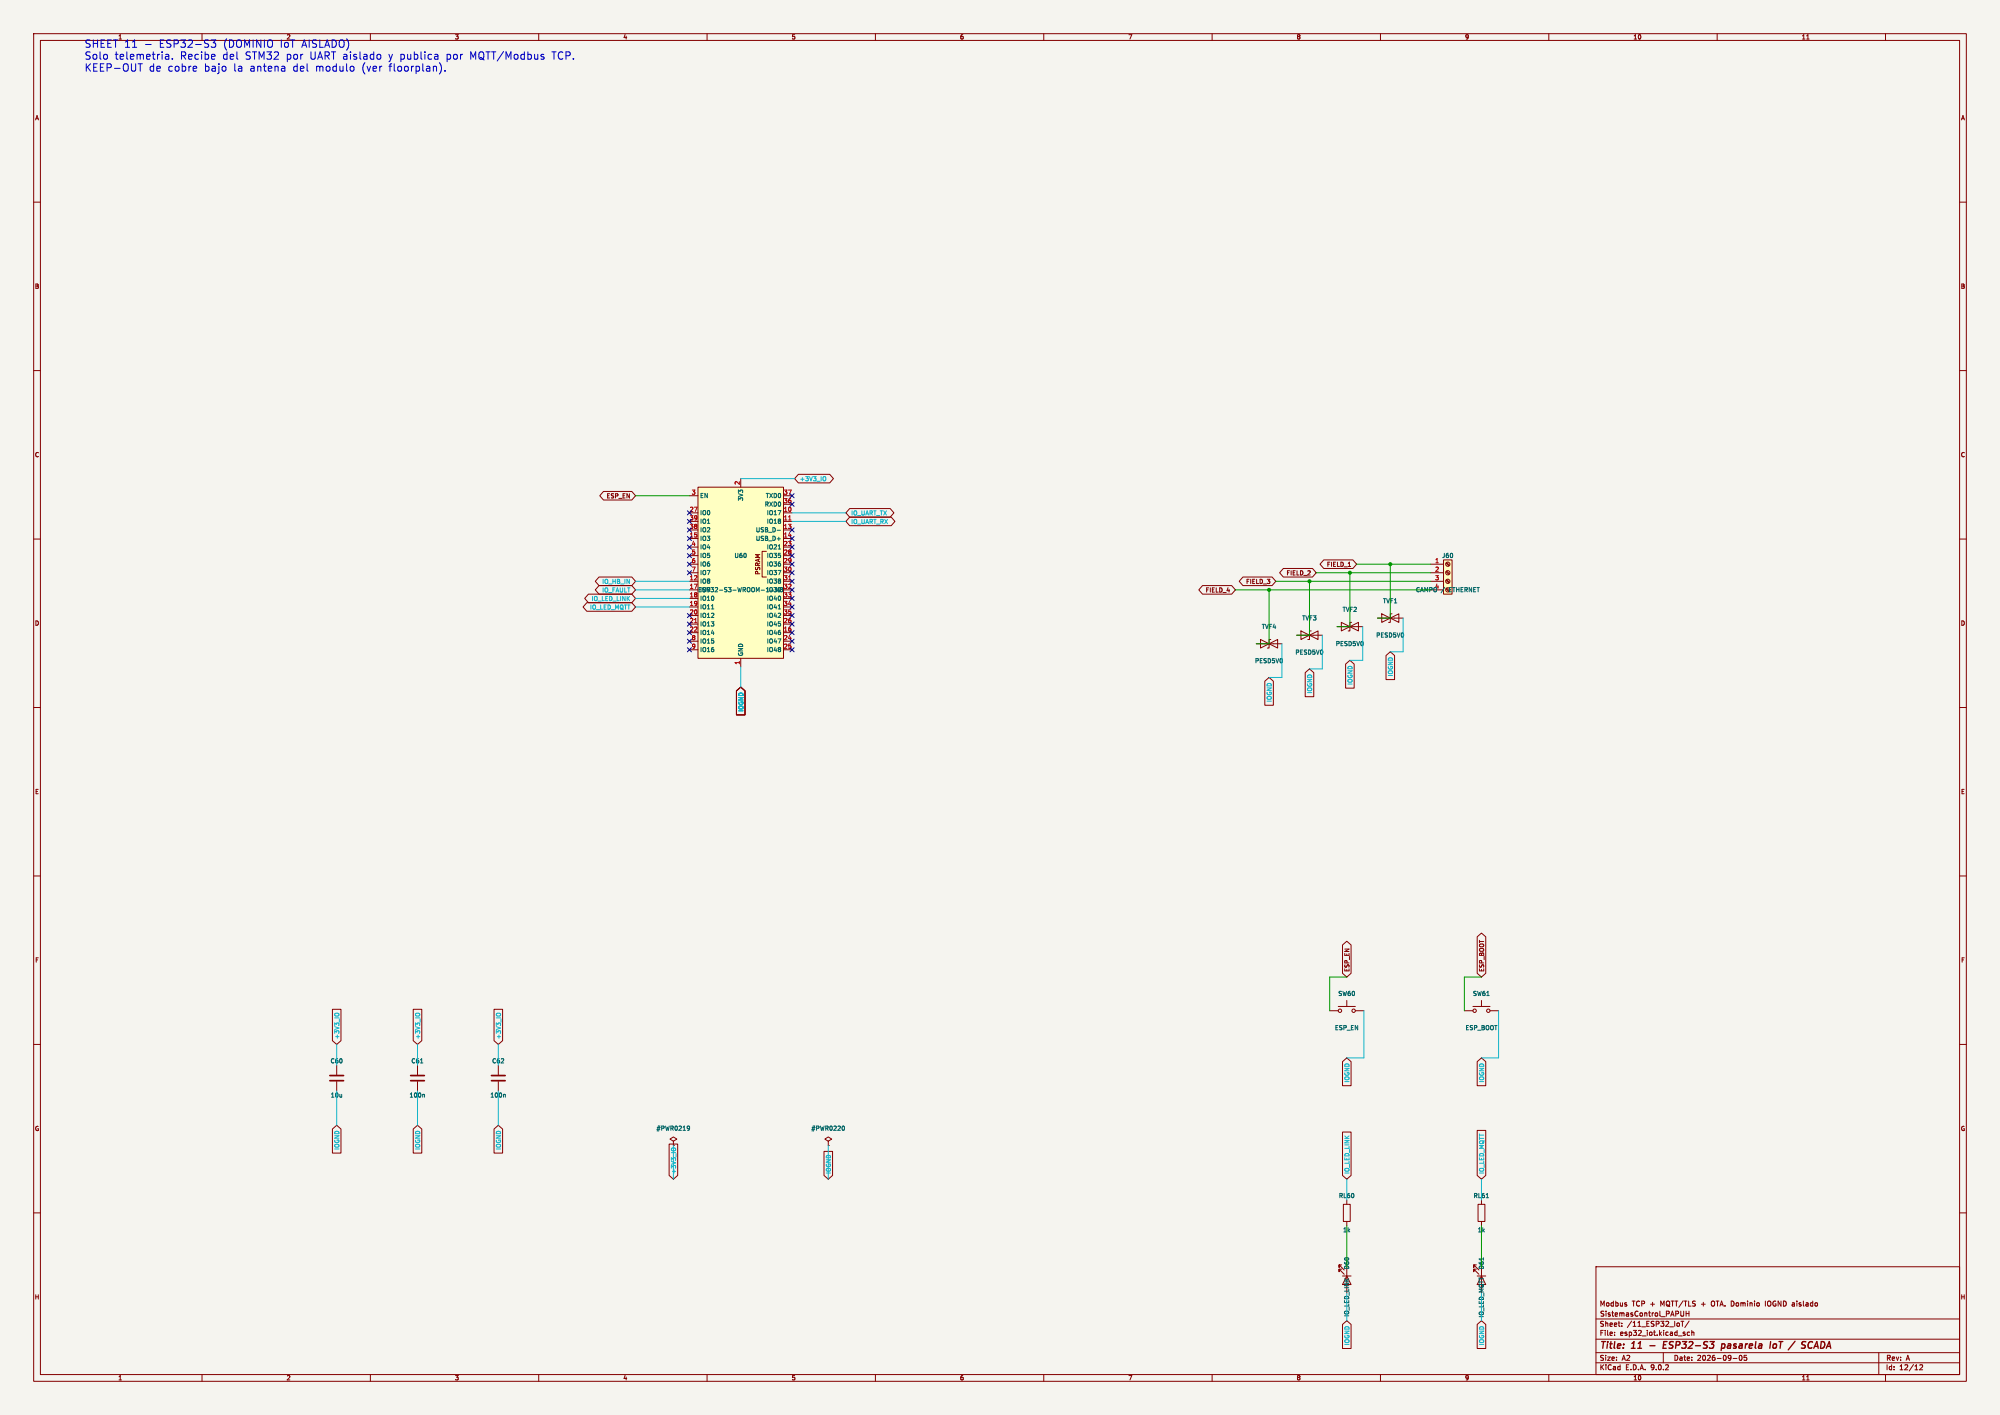
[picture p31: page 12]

KEEP-OUT de cobre bajo la antena del modulo (ver floorplan).

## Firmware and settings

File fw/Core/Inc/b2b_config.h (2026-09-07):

/* ============================================================
 * b2b_config.h - GENERADO POR fw/config/gen_config.py -- NO EDITAR
 *
 * Fuente unica de verdad: sim/b2b_params.py
 * Las ganancias salen de la MISMA sintonia que se valido en
 * docs/INFORME_VALIDACION.md (31/31 comprobaciones OK).
 * ============================================================ */
#ifndef B2B_CONFIG_H
#define B2B_CONFIG_H

/* ---------------- red y nominales ---------------- */
#define B2B_S_NOM_VA        15000.0f
#define B2B_VLL_RMS         400.0f
#define B2B_VPH_PEAK        326.5986f   /* V pico de fase */
#define B2B_F_GRID          60.0f
#define B2B_W_GRID          376.991118f
#define B2B_I_NOM_RMS       21.6506f
#define B2B_I_PEAK          30.6186f

/* ---------------- bus DC ---------------- */
#define B2B_VDC_REF         700.0f
#define B2B_VDC_MAX         800.0f      /* disparo duro */
#define B2B_VDC_CHOP_ON     770.0f     /* chopper de frenado */
#define B2B_VDC_CHOP_OFF    750.0f
#define B2B_VDC_PRECHG_OK   509.1f  /* cierre de K2 */
#define B2B_C_BUS           0.000600000f

/* ---------------- temporizacion PWM (TIM1 / TIM8) ---------------- */
#define B2B_F_TIM_HZ        170000000f
#define B2B_F_SW_HZ         16000.0f
#define B2B_PWM_ARR         5312u        /* modo centrado */
#define B2B_F_SW_REAL_HZ    16001.51f   /* real con ese ARR */
#define B2B_TS              0.0000624941f
#define B2B_DEADTIME_DTG    85u        /* BDTR.DTG */
#define B2B_DEADTIME_NS     500.0f
#define B2B_ADC_TRIG_CCR4   5304u

/* ---------------- limites de modulacion ---------------- */
#define B2B_VMAX_LIN        404.1452f  /* Vdc/sqrt(3): limite SVPWM lineal */
#define B2B_I_LIM_GRID      48.990f
#define B2B_I_LIM_MOTOR     40.000f

/* ---------------- lazo de corriente de RED (AFE) ---------------- */
#define B2B_KP_IGRID        11.20000000f
#define B2B_KI_IGRID        266.66666667f

/* ---------------- lazo de tension de bus ---------------- */
#define B2B_KP_VDC          0.76231602f
#define B2B_KI_VDC          225.94626537f

/* ---------------- lazo de corriente de MOTOR (FOC) ---------------- */
#define B2B_KP_IMOT         16.00000000f
#define B2B_KI_IMOT         800.00000000f

/* ---------------- lazo de velocidad ---------------- */
#define B2B_KP_SPEED        3.38624339f
#define B2B_KI_SPEED        300.99941211f

/* ---------------- PLL trifasico (entrada NORMALIZADA) ---------------- */
#define B2B_PLL_KP          222.110601f
#define B2B_PLL_KI          24674.011003f
#define B2B_PLL_W0          376.991118f
#define B2B_PLL_LOCK_RAD    0.034907f  /* umbral de enganche */

/* ---------------- filtro LCL (para el desacoplo) ---------------- */
#define B2B_L_GRID          0.002100000f   /* L1 + L2 */
#define B2B_R_GRID          0.050000f

/* ---------------- motor PMSM ---------------- */
#define B2B_POLE_PAIRS      3
#define B2B_LAMBDA_PM       0.350000f
#define B2B_LD              0.003000000f
#define B2B_LQ              0.003000000f
#define B2B_RS              0.150000f
#define B2B_KT              1.575000f

/* ---------------- proteccion ---------------- */
#define B2B_OC_GRID_A       55.11f
#define B2B_OC_MOTOR_A      72.00f
#define B2B_OT_TRIP_C       95.0f
#define B2B_PRECHG_TMO_MS   1000u
#define B2B_LINK_TMO_MS     500u   /* watchdog del enlace con el ESP32 */

#endif /* B2B_CONFIG_H */

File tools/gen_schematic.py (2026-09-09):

"""
gen_schematic.py - Genera el esquematico completo del convertidor back-to-back.

Salida:  kicad/b2b_converter.kicad_sch  +  kicad/sch/*.kicad_sch
Ejecutar con el Python que trae KiCad:
    "C:\\Program Files\\KiCad\\9.0\\bin\\python.exe" tools/gen_schematic.py
"""

import os
import sys

HERE = os.path.dirname(os.path.abspath(__file__))
sys.path.insert(0, HERE)
from kisch import SymbolCache, Schematic, check_schematic  # noqa

ROOT_DIR = os.path.dirname(HERE)
OUT = os.path.join(ROOT_DIR, 'kicad')
SYMDIR = r'C:\Program Files\KiCad\9.0\share\kicad\symbols'
FPDIR = os.path.join(os.path.dirname(SYMDIR), 'footprints')
PROJECT = 'b2b_converter'
ROOT_UUID = 'b2b00000-0000-4000-8000-000000000000'

lib = SymbolCache(SYMDIR)

# ------------------------------------------------------------------ footprints
FP = {
    'R0603':  'Resistor_SMD:R_0603_1608Metric',
    'R1206':  'Resistor_SMD:R_1206_3216Metric',
    'R2512':  'Resistor_SMD:R_2512_6332Metric',
    'RPWR':   'Resistor_THT:R_Axial_Power_L38.0mm_W9.0mm_P45.72mm',
    'C0603':  'Capacitor_SMD:C_0603_1608Metric',
    'C0805':  'Capacitor_SMD:C_0805_2012Metric',
    'C1210':  'Capacitor_SMD:C_1210_3225Metric',
    'CFILM':  'Capacitor_THT:C_Rect_L24.0mm_W10.3mm_P22.50mm_MKT',
    'CDCLK':  'Capacitor_THT:CP_Radial_D35.0mm_P10.00mm_SnapIn',
    'CY':     'Capacitor_THT:C_Disc_D9.0mm_W2.5mm_P5.00mm',
    'D_SMA':  'Diode_SMD:D_SMA',
    'D_SOD':  'Diode_SMD:D_SOD-123',
    'D_TO247': 'Package_TO_SOT_THT:TO-247-2_Vertical',
    'LED0805': 'LED_SMD:LED_0805_2012Metric',
    'SIC':    'Package_TO_SOT_THT:TO-247-4_Vertical',
    'IND_PWR': 'TerminalBlock_Phoenix:TerminalBlock_Phoenix_MKDS-1,5-2_1x02_P5.00mm_Horizontal',
    'SOIC8':  'Package_SO:SOIC-8_3.9x4.9mm_P1.27mm',
    'SOIC16W': 'Package_SO:SOIC-16W_7.5x10.3mm_P1.27mm',
    'SOIC14': 'Package_SO:SOIC-14_3.9x8.7mm_P1.27mm',
    'SOT23-5': 'Package_TO_SOT_SMD:SOT-23-5',
    'SOT23':  'Package_TO_SOT_SMD:SOT-23',
    'LQFP100': 'Package_QFP:LQFP-100_14x14mm_P0.5mm',
    'ESP32':  'RF_Module:ESP32-S3-WROOM-1',
    'XTAL':   'Crystal:Crystal_SMD_3225-4Pin_3.2x2.5mm',
    'TB2':    'TerminalBlock_Phoenix:TerminalBlock_Phoenix_MKDS-1,5-2_1x02_P5.00mm_Horizontal',
    'TB3':    'TerminalBlock_Phoenix:TerminalBlock_Phoenix_MKDS-1,5-3_1x03_P5.00mm_Horizontal',
    'TB4':    'TerminalBlock_Phoenix:TerminalBlock_Phoenix_MKDS-1,5-4_1x04_P5.00mm_Horizontal',
    'PINH4':  'Connector_PinHeader_2.54mm:PinHeader_1x04_P2.54mm_Vertical',
    'PINH3':  'Connector_PinHeader_2.54mm:PinHeader_1x03_P2.54mm_Vertical',
    'SWD':    'Connector_PinHeader_1.27mm:PinHeader_2x05_P1.27mm_Vertical',
    'SWPUSH': 'Button_Switch_SMD:SW_Push_1P1T_NO_CK_KMR2',
    'RELAY':  'TerminalBlock_Phoenix:TerminalBlock_Phoenix_MKDS-1,5-2_1x02_P5.00mm_Horizontal',
    'NETTIE': 'NetTie:NetTie-2_SMD_Pad0.5mm',
    'TP':     'TestPoint:TestPoint_Pad_D2.0mm',
    'FUSE':   'Fuse:Fuseholder_Blade_ATO_Littelfuse_Pudenz_2_Pin',
    'MOV':    'Varistor:RV_Disc_D12mm_W4.6mm_P7.5mm',
    'NTC':    'Resistor_THT:R_Axial_DIN0207_L6.3mm_D2.5mm_P10.16mm_Horizontal',
    'USBC':   'Connector_USB:USB_C_Receptacle_HRO_TYPE-C-31-M-12',
}

# ------------------------------------------------------------------ simbolos
S_R = 'Device:R'
S_C = 'Device:C'
S_CP = 'Device:C_Polarized'
S_L = 'Device:L'
S_D = 'Device:D'
S_LED = 'Device:LED'
S_FUSE = 'Device:Fuse'
S_MOV = 'Device:Varistor'
S_NTC = 'Device:Thermistor'
S_TP = 'Connector:TestPoint'
S_SIC = 'Transistor_FET:C3M0075120K'      # 1200 V TO-247-4 (D,S,DS=Kelvin,G)
S_NMOS = 'Transistor_FET:Q_NMOS_GDS'
S_DRV = 'Driver_FET:UCC21520DW'
S_ISO = 'Isolator:ADuM1401xRW'
S_OPA = 'Amplifier_Operational:LM358'
S_MCU = 'MCU_ST_STM32G4:STM32G474V_B-C-E_Tx'
S_ESP = 'RF_Module:ESP32-S3-WROOM-1'
S_TB4 = 'Connector:Screw_Terminal_01x04'
S_TB3 = 'Connector:Screw_Terminal_01x03'
S_TB2 = 'Connector:Screw_Terminal_01x02'
S_CONN4 = 'Connector_Generic:Conn_01x04'
S_XTAL = 'Device:Crystal_GND24'
S_SW = 'Switch:SW_Push'
S_NT = 'Device:NetTie_2'
S_LDO = 'Regulator_Linear:TLV75801PDBV'
S_TVS = 'Device:D_TVS'
S_ZEN = 'Device:D_Zener'
S_SCH = 'Device:D_Schottky'
S_PTC = 'Device:Polyfuse'

SHEETS = [
    ('01_AC_Input_LCL',      'sch/ac_input_lcl.kicad_sch',      'b2b00000-0000-4000-8000-0000000000a1'),
    ('02_AFE_Bridge',        'sch/afe_bridge.kicad_sch',        'b2b00000-0000-4000-8000-0000000000a2'),
    ('03_DClink_Precharge',  'sch/dclink_precharge.kicad_sch',  'b2b00000-0000-4000-8000-0000000000a3'),
    ('04_Inverter_Bridge',   'sch/inverter_bridge.kicad_sch',   'b2b00000-0000-4000-8000-0000000000a4'),
    ('05_Gate_Drivers',      'sch/gate_driver.kicad_sch',       'b2b00000-0000-4000-8000-0000000000a5'),
    ('06_Sense_I_V',         'sch/sense_iv.kicad_sch',          'b2b00000-0000-4000-8000-0000000000a6'),
    ('07_MCU_STM32',         'sch/mcu_stm32.kicad_sch',         'b2b00000-0000-4000-8000-0000000000a7'),
    ('08_Protection_IO',     'sch/protection_io.kicad_sch',     'b2b00000-0000-4000-8000-0000000000a8'),
    ('09_PSU_Aux_Bias',      'sch/psu_aux.kicad_sch',           'b2b00000-0000-4000-8000-0000000000a9'),
    ('10_Isolation_Comms',   'sch/isolation_comms.kicad_sch',   'b2b00000-0000-4000-8000-0000000000aa'),
    ('11_ESP32_IoT',         'sch/esp32_iot.kicad_sch',         'b2b00000-0000-4000-8000-0000000000ab'),
]


def newsheet(idx, title, comments=()):
    name, fn, su = SHEETS[idx]
    return Schematic(title, lib, PROJECT, ROOT_UUID, su,
                     paper='A2', comments=comments)


# ============================================================ helpers de dibujo

def vres(sch, ref, val, x, y, fp='R0603'):
    """Resistencia vertical. Devuelve (arriba, abajo)."""
    p = sch.place(S_R, ref, val, x, y, 0, footprint=FP[fp])
    return p, p.pin('1'), p.pin('2')


def hres(sch, ref, val, x, y, fp='R0603'):
    p = sch.place(S_R, ref, val, x, y, 90, footprint=FP[fp])
    return p, p.pin('1'), p.pin('2')      # (izq, der)


def vcap(sch, ref, val, x, y, fp='C0603', sym=S_C):
    p = sch.place(sym, ref, val, x, y, 0, footprint=FP[fp])
    return p, p.pin('1'), p.pin('2')


def hcap(sch, ref, val, x, y, fp='C0603', sym=S_C):
    p = sch.place(sym, ref, val, x, y, 90, footprint=FP[fp])
    return p, p.pin('1'), p.pin('2')


def h2pin(sch, sym, ref, val, x, y, fp):
    """Cualquier simbolo de 2 pines, horizontal. Devuelve (obj, izq, der)."""
    p = sch.place(sym, ref, val, x, y, 90, footprint=FP[fp])
    return p, p.pin('1'), p.pin('2')


def vind(sch, ref, val, x, y, fp='IND_PWR'):
    p = sch.place(S_L, ref, val, x, y, 0, footprint=FP[fp])
    return p, p.pin('1'), p.pin('2')


def hind(sch, ref, val, x, y, fp='IND_PWR'):
    p = sch.place(S_L, ref, val, x, y, 90, footprint=FP[fp])
    return p, p.pin('1'), p.pin('2')


def decouple(sch, ref, val, x, y, net_top, gnd='GND', fp='C0603'):
    """Condensador de desacoplo a GND con etiqueta arriba."""
    c, t, b = vcap(sch, ref, val, x, y, fp)
    sch.wire(t, (x, y - 6.35))
    sch.label(net_top, (x, y - 6.35), 90)
    sch.power(gnd, b)
    return c



def rail(sch, y, extra_x=(), label=None, rot=180, x0=None, x1=None,
         xmin=None, xmax=None):
    """Dibuja un riel horizontal PARTIDO en cada punto donde algo lo toca.

    KiCad solo une cables extremo-con-extremo: un cable que muere en mitad
    de otro NO conecta, ni poniendo una junction. Por eso el riel no puede
    ser un unico segmento largo. Esta funcion busca los extremos de cable
    que ya aterrizan en la altura `y` y construye el riel entre ellos.
    """
    from kisch import _find, _findall, Sym
    xs = set(float(v) for v in extra_x)
    for it in sch.items:
        if not (isinstance(it, list) and it and it[0] == Sym('wire')):
            continue
        pts = _find(it, Sym('pts'))
        for c in _findall(pts, Sym('xy')):
            if abs(float(c[2]) - y) < 1e-6:
                xs.add(round(float(c[1]), 4))
    if x0 is not None:
        xs.add(float(x0))
    if x1 is not None:
        xs.add(float(x1))
    # xmin/xmax acotan el riel: sin ellos se tragaria nodos vecinos que estan
    # a la misma altura pero son OTRA red (p.ej. DC_RAW antes de la
    # resistencia de precarga, que quedaria puenteada).
    if xmin is not None:
        xs = {x for x in xs if x >= xmin - 1e-6}
    if xmax is not None:
        xs = {x for x in xs if x <= xmax + 1e-6}
    xs = sorted(xs)
    if len(xs) < 2:
        return xs
    for a, b in zip(xs, xs[1:]):
        sch.wire((a, y), (b, y))
    for xj in xs[1:-1]:
        sch.junction((xj, y))
    if label:
        px = xs[-1] if rot == 0 else xs[0]
        sch.glabel(label, (px, y), rot, 'bidirectional')
    return xs


# ============================================================ SHEET 01 - LCL

def sheet01():
    sch = newsheet(0, '01 - Entrada AC + Filtro LCL',
                   ('Red 3~ 400 V 60 Hz -> EMC -> LCL -> puente AFE',
                    'L1=1.5 mH  Cf=10 uF  Rd=2.2 ohm  L2=0.6 mH  fres=2.4 kHz'))
    sch.text('SHEET 01 - ENTRADA AC + FILTRO LCL\n'
             'Orden fisico: RED -> fusible -> contactor -> choke CM -> L2(red) '
             '-> [Cf+Rd al neutro] -> L1(conv) -> puente AFE\n'
             'Clase de red: HV_AC (clearance 3.0 mm / creepage 4.0 mm)',
             (25, 15), size=2.2)

    J1 = sch.place(S_TB4, 'J1', 'RED 3~ + PE', 45, 60, 180, footprint=FP['TB4'])
    phases = ['L1', 'L2', 'L3']
    ys = [50, 70, 90]
    for i, (ph, y) in enumerate(zip(phases, ys)):
        pin = J1.pin(str(i + 1))
        # columna propia por fase: si compartieran x se cortocircuitarian
        colx = 54 + i * 5
        sch.wire(pin, (colx, pin[1]))
        sch.wire(sch.wire(( colx, pin[1]), (colx, y)) or (colx, y), (72, y))
        # fusible
        f, fa, fb = h2pin(sch, S_FUSE, 'F%d' % (i + 1), '25A aR', 82, y,
                          'FUSE')
        sch.wire((72, y), fa)
        sch.wire(fb, (100, y))
        # choke de modo comun (3 devanados acoplados)
        lcm, la, lb = hind(sch, 'LCM%d' % (i + 1), '3mH CM', 118, y)
        sch.wire((100, y), la)
        sch.label('GRID_%s' % ph, ((la[0] + lb[0]) / 2, y - 3.0), 0)
        # L2 lado red
        l2, l2a, l2b = hind(sch, 'L2%s' % 'ABC'[i], '0.6mH', 148, y)
        sch.wire(lb, l2a)
        # nodo intermedio LCL
        node = (172, y)
        sch.wire(l2b, node)
        sch.junction(node)
        sch.label('LCL_%s' % 'ABC'[i], (172, y - 3.0), 0)
        # L1 lado convertidor
        l1, l1a, l1b = hind(sch, 'L1%s' % 'ABC'[i], '1.5mH', 196, y)
        sch.wire(node, l1a)
        sch.wire(l1b, (216, y))
        sch.glabel('AFE_%s' % 'ABC'[i], (216, y), 0, 'bidirectional')
        # sensado de tension de red
        sch.glabel('GRID_%s' % ph, (128, y - 12), 0, 'output')
        sch.wire((124, y), (124, y - 12))
        sch.wire((124, y - 12), (128, y - 12))
        sch.junction((124, y))

    # PE del conector
    pe = J1.pin('4')
    sch.wire(pe, (48, pe[1]))
    sch.wire((48, pe[1]), (48, 130))
    sch.label('PE', (48, 130), 0)
    sch.power('PE', (60, 130)) if False else None

    # --- banco de MOV (unido por etiqueta, sin cruzar fases) ---
    for i, ph in enumerate(['L1', 'L2', 'L3']):
        x = 96 + i * 18
        mov = sch.place(S_MOV, 'RV%d' % (i + 1), '20D471K', x, 168, 0,
                        footprint=FP['MOV'])
        sch.wire(mov.pin('1'), (x, 158))
        sch.label('GRID_%s' % ph, (x, 158), 90)
        sch.wire(mov.pin('2'), (x, 178))
        sch.label('PE', (x, 178), 270)
    sch.box(86, 148, 148, 186, 'PROTECCION DE SOBRETENSION (MOV clase II)',
            size=1.8)

    # --- banco Cf + Rd del LCL (unido por etiqueta) ---
    for i, ltr in enumerate('ABC'):
        x = 168 + i * 20
        rd, rda, rdb = vres(sch, 'RD%s' % ltr, '2R2 10W', x, 168, 'RPWR')
        sch.wire(rda, (x, 158))
        sch.label('LCL_%s' % ltr, (x, 158), 90)
        cf, cfa, cfb = vcap(sch, 'CF%s' % ltr, '10uF 500VAC', x, 186, 'CFILM')
        sch.wire(rdb, cfa)
        sch.wire(cfb, (x, 196))
        sch.label('LCL_N', (x, 196), 270)
    sch.box(158, 148, 216, 204, 'RAMA Cf + Rd DEL LCL  (amortiguamiento)',
            size=1.8)

    # neutro del banco Cf: referencia a PE por Y-caps
    for i, ref in enumerate(['CY1', 'CY2', 'CY3']):
        c, a, b = vcap(sch, ref, '4n7 Y2', 210 + i * 14, 128, 'CY')
        sch.wire(a, (210 + i * 14, 118))
        sch.label('LCL_N', (210 + i * 14, 118), 0)
        sch.wire(b, (210 + i * 14, 140))
        sch.label('PE', (210 + i * 14, 140), 0)

    # caps X de modo diferencial
    for i, (ref, na, nb) in enumerate([('CX1', 'GRID_L1', 'GRID_L2'),
                                       ('CX2', 'GRID_L2', 'GRID_L3')]):
        c, a, b = vcap(sch, ref, '470n X2', 262 + i * 18, 128, 'CFILM')
        sch.wire(a, (262 + i * 18, 118))
        sch.label(na, (262 + i * 18, 118), 0)
        sch.wire(b, (262 + i * 18, 140))
        sch.label(nb, (262 + i * 18, 140), 0)

    sch.box(140, 36, 232, 108,
            'FILTRO LCL: L2(red) - nodo - L1(conv).  fres = 2.4 kHz')
    sch.box(66, 36, 140, 108, 'PROTECCION + EMC DE ENTRADA')
    return sch


# ============================================================ medio puente SiC

def halfbridge(sch, x, ytop, ybot, qh, ql, swnet, idx, cdec_ref):
    """Dibuja una rama de medio puente SiC entre DC_P (ytop) y DC_N (ybot)."""
    ymid = (ytop + ybot) / 2.0
    Qh = sch.place(S_SIC, qh, 'C3M0075120K', x, ytop + 26, 0,
                   footprint=FP['SIC'])
    Ql = sch.place(S_SIC, ql, 'C3M0075120K', x, ybot - 26, 0,
                   footprint=FP['SIC'])
    # drain alto -> riel DC_P (bajada vertical; el riel se dibuja despues
    # PARTIDO en estos mismos puntos, ver bridge_sheet)
    dxh = Qh.pin('1')[0]
    sch.wire(Qh.pin('1'), (dxh, ytop))
    # source alto -> nodo de conmutacion
    sch.wire_l(Qh.pin('2'), (x, ymid), first='v')
    # drain bajo -> nodo de conmutacion
    sch.wire_l(Ql.pin('1'), (x, ymid), first='v')
    sch.junction((x, ymid))
    # source bajo -> riel DC_N (mismo criterio: bajada vertical, T sobre riel)
    sxl = Ql.pin('2')[0]
    sch.wire(Ql.pin('2'), (sxl, ybot))
    # salida del nodo
    sch.wire((x, ymid), (x + 22, ymid))
    sch.glabel(swnet, (x + 22, ymid), 0, 'bidirectional')
    # gate y kelvin
    for Q, tag in ((Qh, 'H%d' % idx), (Ql, 'L%d' % idx)):
        g = Q.pin('4')
        k = Q.pin('3')
        sch.wire(g, (g[0] - 12, g[1]))
        sch.glabel('G_%s' % tag, (g[0] - 12, g[1]), 180, 'input')
        sch.wire(k, (k[0] + 12, k[1]))
        sch.glabel('K_%s' % tag, (k[0] + 12, k[1]), 0, 'passive')
    # --- PROTECCION DE PUERTA ---
    # TVS bidireccional gate-source en CADA SiC. Sin ella, un pico de dv/dt
    # acoplado por Cgd puede perforar el oxido de puerta: es el modo de
    # fallo mas comun en SiC. Va fisicamente en el pie del transistor.
    for Q, tag, ytv in ((Qh, 'H%d' % idx, ytop + 40),
                        (Ql, 'L%d' % idx, ybot - 12)):
        tv = sch.place(S_TVS, 'TVG%s' % tag, '+20/-6V', x - 44, ytv, 0,
                       footprint=FP['D_SOD'])
        sch.wire(tv.pin('1'), (x - 44, ytv - 12))
        sch.label('G_%s' % tag, (x - 44, ytv - 12), 90)
        sch.wire(tv.pin('2'), (x - 44, ytv + 12))
        sch.label('K_%s' % tag, (x - 44, ytv + 12), 270)

    # --- SNUBBER RC DEL NODO DE CONMUTACION ---
    # 220 pF + 4.7 ohm: valor que sale del barrido en LTspice. Baja el dv/dt
    # de 147 a 90 V/ns (por debajo del CMTI de 100 V/ns del UCC21520) y la
    # sobretension de 823 a 767 V, a costa de 10 W en los 12 dispositivos.
    sx = x + 40
    csn, ca, cb = vcap(sch, 'CSN%s' % swnet[-1], '220p 1kV', sx, ymid + 16,
                       'CFILM')
    sch.wire((x + 22, ymid), (sx, ymid))
    sch.junction((x + 22, ymid))
    sch.wire((sx, ymid), ca)
    rsn, ra, rb = vres(sch, 'RSN%s' % swnet[-1], '4R7 2W', sx, ymid + 40,
                       'R2512')
    sch.wire(cb, ra)
    sch.wire(rb, (sx, ybot))

    # decoupling de lazo de conmutacion
    cx = x - 26
    c, a, b = vcap(sch, cdec_ref, '1uF 1kV', cx, ymid, 'CFILM')
    sch.wire(a, (a[0], ytop))
    sch.wire(b, (b[0], ybot))
    # x donde esta rama toca cada riel
    return [dxh, a[0]], [sxl, b[0], sx]


def bridge_sheet(idx, title, comments, qbase, gbase, nets, note):
    sch = newsheet(idx, title, comments)
    sch.text(note, (25, 15), size=2.2)
    ytop, ybot = 60, 200
    x0 = 90
    dx = 88
    xp, xn = [x0 - 30], [x0 - 30]
    for i in range(3):
        tp, tn = halfbridge(sch, x0 + i * dx, ytop, ybot,
                            '%s%d' % (qbase, 2 * i + 1),
                            '%s%d' % (qbase, 2 * i + 2),
                            nets[i], gbase + i, 'CD%s' % nets[i][-1])
        xp += tp
        xn += tn
        sch.box(x0 + i * dx - 36, ytop - 8, x0 + i * dx + 36, ybot + 8,
                'RAMA %s' % nets[i][-1], size=2.0)

    # Rieles DC dibujados como segmentos PARTIDOS en cada punto de contacto.
    # KiCad NO conecta un cable que termina en mitad de otro aunque se ponga
    # una junction: solo une extremos con extremos. Con el riel de una pieza,
    # todas las ramas menos la ultima quedaban fuera del bus.
    for xs, y, nombre in ((sorted(set(xp)), ytop, 'DC_P'),
                          (sorted(set(xn)), ybot, 'DC_N')):
        for a, b in zip(xs, xs[1:]):
            sch.wire((a, y), (b, y))
        for xj in xs[1:-1]:
            sch.junction((xj, y))
        sch.glabel(nombre, (xs[0], y), 180, 'bidirectional')
    sch.text('LAZO DE CONMUTACION: el condensador de 1 uF/1 kV va a menos de\n'
             '10 mm del par de MOSFET. Objetivo L_lazo < 20 nH.',
             (25, 225), size=2.0)
    return sch


def sheet02():
    return bridge_sheet(
        1, '02 - Puente AFE (Active Front End)',
        ('6x SiC 1200 V - rectificador activo PWM - fsw 16 kHz',),
        # El nodo de conmutacion del AFE y la salida del LCL son EL MISMO
        # nodo fisico. Si no se llaman igual, el puente queda desconectado
        # del filtro (AFE_x colgaba sola en L1x).
        'Q', 1, ['AFE_A', 'AFE_B', 'AFE_C'],
        'SHEET 02 - PUENTE AFE\n'
        'Ramas A/B/C. El nodo de conmutacion ES la salida del LCL (AFE_x).\n'
        'Gates G_H1..3 / G_L1..3 y Kelvin K_H1..3 / K_L1..3 al sheet 05.')


def sheet04():
    sch = bridge_sheet(
        3, '04 - Puente Inversor (lado motor)',
        ('6x SiC 1200 V - FOC - salida U/V/W al motor',),
        'Q', 4, ['SW_U', 'SW_V', 'SW_W'],
        'SHEET 04 - PUENTE INVERSOR\n'
        'Ramas U/V/W. Gates G_H4..6 / G_L4..6 y Kelvin al sheet 05.\n'
        'Salida a bornera de motor con PE y abrazadera de malla 360 grados.')
    # renombrar los MOSFET a Q7..Q12
    n = 7
    for p in sch.placed:
        if p.lib_id == S_SIC:
            p.ref = 'Q%d' % n
            n += 1
    # bornera de motor
    JM = sch.place(S_TB4, 'J4', 'MOTOR U/V/W/PE', 420, 120, 0,
                   footprint=FP['TB4'])
    for i, net in enumerate(['SW_U', 'SW_V', 'SW_W']):
        pin = JM.pin(str(i + 1))
        sch.wire(pin, (pin[0] - 20, pin[1]))
        sch.glabel(net, (pin[0] - 20, pin[1]), 180, 'input')
    pe = JM.pin('4')
    sch.wire(pe, (pe[0] - 20, pe[1]))
    sch.label('PE', (pe[0] - 20, pe[1]), 180)
    # NTC de disipador
    for i, ref in enumerate(['RT1', 'RT2']):
        t = sch.place(S_NTC, ref, '10k B3950', 400 + i * 30, 200, 0,
                      footprint=FP['NTC'])
        sch.wire(t.pin('1'), (400 + i * 30, 190))
        sch.glabel('NTC%d' % (i + 1), (400 + i * 30, 190), 90, 'output')
        sch.wire(t.pin('2'), (400 + i * 30, 210))
        sch.power('GND', (400 + i * 30, 210))
    sch.text('RT1 = disipador   RT2 = cuerpo de modulo', (392, 218), size=1.8)
    return sch


# ============================================================ SHEET 03 - BUS DC
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

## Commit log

2026-09-07 Convertidor back-to-back AFE + inversor 15 kVA / 800 V
    Diseno completo generado por script y validado por simulacion.
    Esquematico y PCB (KiCad 9)
    - 11 hojas, 227 componentes, 130 redes, 0 cables sueltos
    - PCB 340x240 mm, 4 capas, colocada con zonas rellenadas
    - Barrera de aislamiento como rule area ISO_BARRIER
    - Reglas DRC custom de creepage/clearance (IEC 60664-1 / IPC-2221B)
    Validacion (31/31 comprobaciones OK)
    - Simulacion temporal red -> AFE -> bus DC -> inversor FOC -> PMSM
    con frenado regenerativo: bus a 700 V, FP unitario, -11 kW a la red
    - SPICE en LTspice: doble pulso del medio puente con parasitas
    - Contraste cruzado del LCL: analitico vs SPICE, 0.027 dB de diferencia
    Hallazgo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
    [ac_input_lcl.kicad_sch, afe_bridge.kicad_sch, b2b_converter.kicad_pcb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]
2026-09-08 Corrige tres bugs de conectividad del bus DC y anade guia de simulacion
    Al intentar rutear los lazos de conmutacion aparecieron tres errores graves
    del esquematico que ninguna revision visual habia detectado:
    1. Los rieles del bus DC solo conectaban la ULTIMA rama de cada puente.
    DC_P tenia 4 pads en vez de 22; Q1, Q3, Q7 y Q9 quedaban unconnected.
    Causa: el riel era un unico cable largo y los stubs de cada rama morian
    en mitad de el. KiCad solo une cables extremo con extremo: un cable que
    termina en medio de otro NO conecta, ni con junction. Solo funcionaba la
    ultima rama porque coincidia con el extremo del riel.
    Corregido con un helper rail() que construye el riel PARTID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
    [ac_input_lcl.kicad_sch, afe_bridge.kicad_sch, b2b_converter.kicad_pcb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]
2026-09-08 Anade las graficas de respuesta dinamica que faltaban
    Nuevo sim/sim_respuesta.py, integrado en run_all (36/36 comprobaciones):
    20 Respuesta al escalon en lazo cerrado (corriente y bus), con
    sobreimpulso, tiempo de subida y de establecimiento anotados.
    Retardo aproximado con Pade [2/2] escrito a mano: scipy.signal.pade
    no existe en scipy 1.16.
    21 CARGA TRANSITORIA: escalon 20 % -> 100 % -> 20 % sobre el bus DC,
    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
2026-09-08 Anade el diagrama de sectores y vectores SVPWM (38/38)
    sim/sim_svpwm.py, integrado en run_all:
    26 Hexagono con los 6 vectores activos, los 2 nulos, los 6 sectores, el
    circulo inscrito (limite lineal Vdc/sqrt(3) = 404 V) y la
    descomposicion Vref = T1*V1 + T2*V2 en el sector 1.
    27 Ciclos de trabajo vs angulo comparados con el SPWM senoidal (la
    "silla" de la inyeccion de secuencia cero), el tercer armonico
    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
2026-09-08 Hace ejecutable por separado cada modulo de simulacion
    Antes solo run_all.py y sim_svpwm.py tenian bloque __main__: intentar
    lanzar sim_design.py suelto no producia nada. Ahora los cinco modulos de
    sim/ se ejecutan de forma independiente y generan solo sus figuras:
    python sim\b2b_params.py punto de diseno
    python sim\sim_design.py figuras 01-03
    python sim\sim_timedomain.py figuras 04-05
    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
2026-09-08 Corrige el doc de simulacion: rutas mutiladas por escapado y conteos
    Al generar el bloque de comandos por script, las secuencias \b y \r se
    interpretaron como bytes de control y se comieron letras: quedaba
    'python sim2b_params.py' y 'python sim' + salto + 'un_all.py'.
    Reescrito localizando el bloque por su encabezado y filtrando los bytes
    de control. Actualizados tambien los conteos de 31 a 38 comprobaciones.
2026-09-09 Anade protecciones electricas y stackup con color
    PROTECCIONES (de 15 a 56 componentes de proteccion, 272 en total)
    12x TVS gate-source, una por SiC. Sin ella un pico de dv/dt acoplado
    por Cgd puede perforar el oxido de puerta: es el modo de fallo mas
    comun en SiC. Va en el pie del transistor.
    12x snubber RC del nodo de conmutacion (220 pF + 4.7 ohm). El valor sale
    del barrido en LTspice: baja el dv/dt de 147 a 90 V/ns, por debajo
    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
    [ac_input_lcl.kicad_sch, afe_bridge.kicad_sch, b2b_converter.kicad_pcb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]
